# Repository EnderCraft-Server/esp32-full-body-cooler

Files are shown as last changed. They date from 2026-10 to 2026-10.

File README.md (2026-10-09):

# ESP32 全身降温器（背包式水冷） — `esp32-full-body-cooler`

用 ESP32-S3 主控 + 冰袋 + 365 隔膜泵 + 贴身软管循环水，做一件可以背着走的全身降温马甲。

```
冰袋 + 水 -> PET 密封罐 -> 365 泵 -> 8x11 软管（贴身循环）-> 回 PET 罐
                    ^                                  |
                    +---- DS18B20 水温 / 体表温度 ------+
                                  |
            ESP32-S3 -> 继电器 -> 泵间歇启停（慢 PWM）
```

**核心约束**：365 隔膜泵是有刷电机，**不能用 PWM 平滑调速**，只能整段启停。
固件用「回差 + 最短启停时间」做间歇控制 —— 本质是周期以秒/分钟计的慢 PWM。

---

## 仓库结构

```
esp32-full-body-cooler/
├── projects/
│   ├── body-cooler/          ★ 主项目（固件 + 文档 + CAD）
│   │   ├── src/              main / tempsensor / controller / inputs / console
│   │   ├── include/          config.h 是唯一的引脚与参数来源
│   │   ├── docs/             接线、密封、BOM、PCB 简报等 14 篇
│   │   ├── cad/              防折螺旋护套（3D 打印件）+ 生成脚本
│   │   └── wiring.html       交互式接线图（可隐藏单个元件、电流动画）
│   └── hello-s3/             参考工程：芯片自检 + PSRAM 读写测试
├── scripts/                  PlatformIO 工作区工具（见下）
├── skills/esp32-platformio/  可复用的 ESP32 开发 Skill
└── .pio-proxy                本地代理地址（一行），pio.ps1 自动探测启用
```

工作区是**自包含**的：Python venv、PlatformIO core dir、下载缓存、TEMP 全都在文件夹里，
不往用户目录写东西 —— 删掉整个文件夹即彻底卸载。

---

## 快速开始

```powershell
# 编译
.\scripts\pio.ps1 run -d .\projects\body-cooler

# 编译 + 烧录（串口必须显式指定）
.\scripts\pio.ps1 run -d .\projects\body-cooler -t upload --upload-port COM6

# 看串口（pio device monitor 在无 TTY 环境下不可用，用这个）
.venv\Scripts\python.exe .\scripts\serial_term.py --port COM6      # 交互式，能发命令
.venv\Scripts\python.exe .\scripts\serial_capture.py --port COM6 --seconds 10 --reset

# 脚本化发命令并抓回复
.venv\Scripts\python.exe .\scripts\serial_cmd.py --port COM6 --step "scan" --step "status@2"
```

`-d` 必须写在子命令**后面**。

**首次或换机器**：

```powershell
.\scripts\bootstrap.ps1        # 从零重建 venv + PlatformIO（约 700 MB）
```

---

## 硬件要点（踩过坑的，别再踩）

| 事项 | 结论 |
|---|---|
| **继电器触发电平** | 模块是**低电平触发(L)**：IN 短接 GND 吸合 |
| **继电器驱动方式** | 必须**开漏**：吸合推低 0V，释放引脚**高阻**。**绝不能推 3.3V** —— 模块 VCC 是 5V，光耦 LED 阴极接 IN，3.3V 时仍有微弱电流把继电器维持住，表现就是「说 pump=OFF 却一直转」 |
| **泵的电流路径** | `电池+ → 保险丝 → 继电器 COM → NO → 泵+ → 泵− → 电池−`，中间**不能有任何降压板** |
| **续流二极管** | 必须装，1N5822 反向并联在泵两端，阴极朝泵+ |
| **泵保护** | 软管一折就瘪 → 憋压 → 烧泵（已烧 2 台）。三道防线：水流传感器 / `maxrun` 连续运行上限 / **KSD9700 70°C 串在泵电源线上** |
| **贴身软管** | 6×8 硅胶管壁厚只有 1mm，压一下就瘪且撑不开。用 `cad/` 里的**防折螺旋护套**，或嵌进开槽 EVA 垫 |
| **DS18B20 角色映射** | NVS 键名上限 **15 字符**，早期版本用 `role_<16位ROM>`（21 字符）静默写入失败 → 重启后角色丢失 → 安全联锁锁死泵 |

完整踩坑记录见 `projects/body-cooler/docs/BENCH-TEST.md`。

---

## 文档索引

入口：**`projects/body-cooler/README.md`** —— 其中的
**「接线口述（控制端 + 输入端）」**一节是完整的分步接线说明（含逐条接线表，不含电容）。

| 文档 | 内容 |
|---|---|
| `docs/PROJECT-STATUS.md` | 当前状态、已完成 / 待办 |
| `docs/WIRING-CHECKLIST.md` | ★★ **逐触点接线总表：85 根线逐根列，接完打勾，用来事后复原** |
| `docs/BENCH-TEST.md` | ★ 台架测试、事故记录、上电前检查表 |
| `docs/WIRING-GUIDE.md` | 接线总览与电路原理 |
| `docs/GPIO-MAP.md` | GPIO 完整映射（含禁用脚说明） |
| `docs/SEALING-REVIEW.md` | ★ 密封、冷凝、软管被吸瘪的排查 |
| `docs/BOM.md` | 采购清单（具体型号 + 搜索关键词 + 避坑） |
| `docs/PCB-BRIEF.md` | 给硬件工程师的 PCB 设计简报 |
| `docs/diagrams/` | 原理图与示意图（PNG + 生成脚本） |
| `hardware/README.md` | ★ 原理图源文件：嘉立创EDA 导入步骤、网络名一览、元件清单 |
| `cad/README.md` | ★ 3D 打印件：防折螺旋护套 + 转角导弯件 |

---

## 工具链版本

| 组件 | 版本 |
|---|---|
| Python | 3.14.7 |
| PlatformIO Core | 6.2.0 |
| platform | `espressif32@7.1.3` |
| framework | arduino-esp32 2.0.17（ESP-IDF 4.4.7） |
| 编译器 | xtensa-esp32s3 GCC 8.4.0 |
| 烧录器 | esptool 4.11.0 |
| 目标板 | ESP32-S3 **N16R8** — 16 MB QIO flash + 8 MB OPI PSRAM |

---

## 工作区工具（`scripts/`）

| 脚本 | 作用 |
|---|---|
| `pio.ps1` | 唯一的 pio 入口，自动配好所有环境变量与代理 |
| `env.ps1` | 在当前会话 dot-source 出 pio 函数 |
| `bootstrap.ps1` | 从零重建整个环境 |
| `serial_term.py` / `term.ps1` | 交互式串口终端（收 + 发） |
| `serial_capture.py` / `monitor.ps1` | 非交互串口抓取 |
| `serial_cmd.py` | 脚本化发命令并抓回复，支持 `cmd@秒数` |
| `new_project.ps1` | 按模板新建工程 |
| `dsh_sandbox_shim.py` | 修沙箱下 `tempfile.mkdtemp()` 的 PermissionError |

**两个环境适配点，别当成多余代码删掉**：

1. `dsh_sandbox_shim.py` — 沙箱通过父目录的可继承 ACE 授予写权限，
   而 Python 的 `tempfile.mkdtemp()` 会写入显式 DACL 把继承的 ACE 顶掉，
   导致 pip / ensurepip 无法暂存文件。补丁由 `bootstrap.ps1` 装成 venv 的
   `sitecustomize.py`，必须早于 `ensurepip`。
2. `.pio-proxy` — 直连 `dl.registry.platformio.org` 实测 ~17 kB/s，
   走本地代理 ~248 kB/s。`pio.ps1` 探测端口可达后自动启用，不通则回退直连。

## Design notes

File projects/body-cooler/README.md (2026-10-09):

# body-cooler —— ESP32 全身降温器（背包式）

用 ESP32-S3 主控，通过 8x11 软管循环冰水实现全身散热。冰袋方案，不用 TEC。
**365 隔膜泵是有刷电机，只能整段启停，不能 PWM 平滑调速** —— 固件用
「回差 + 最短启停时间」做间歇控制，本质是**周期以秒/分钟计的慢 PWM**。

```
冰袋 + 500ml 水 -> PET 密封罐 -> 365 泵 -> 8x11 软管（贴身循环）-> 回 PET 罐
                        ^                                    |
                        └──── DS18B20 测水温 / 体表温度 ──────┘
                                        |
                                  ESP32 -> 继电器 -> 泵间歇启停
```

---

## 目录结构

```
body-cooler/
  platformio.ini            PlatformIO 配置（ESP32-S3-N16R8）
  include/
    config.h                引脚分配、默认参数、编译开关
    tempsensor.h            DS18B20 多探头异步采集 + 角色映射
    controller.h            水泵控温状态机
    inputs.h                v2 输入层（电池/水流/液位/急停/漏水）
    console.h               串口命令行
  src/
    main.cpp                主循环、状态灯、蜂鸣器、备用继电器
    tempsensor.cpp
    controller.cpp
    inputs.cpp
    console.cpp
  docs/
    WIRING-GUIDE.md         ★ 接线总览与电路原理（配三张原理图）
    ORDER-REVIEW.md         京东订单核对（哪些买错、还要补什么）
    GPIO-MAP.md             ★ GPIO 完整映射表（v1/v2/禁用脚/接线图）
    UPGRADE-PLAN.md         ★ 分阶段升级方案（P0~P4）
    BOM.md                  ★ 采购清单（具体型号 + 搜索关键词 + 避坑）
    WIRING-REVIEW.md        接线与电源审查（必读，有 6 处必须改）
    SEALING-REVIEW.md       ★ 密封、冷凝、软管被吸瘪的排查
    BRINGUP.md              桌面测试 7 步流程（必读，别跳步）
    PCB-BRIEF.md            ★ PCB 设计规格书（交给硬件工程师画板用）
    WIRING-CHECKLIST.md     ★★ 逐触点接线总表（85 根线，接完打勾，事后复原用）
    BENCH-TEST.md           ★★ 台架测试 + 事故记录 + 上电前 10 条检查
    PROJECT-STATUS.md       当前状态：已完成 / 卡脖子的 / 下一步
  docs/diagrams/            原理图与示意图（PNG + 生成脚本 fig*.py）
    fig1_power_pump.png     图1 电源分配与水泵主回路
    fig2_esp32_wiring.png   图2 ESP32-S3 全部引脚接线
    fig3_water_loop.png     图3 水路走向与保温结构
    fig4_build_methods.png  图4 搭建方式对比
    fig5_system_schematic.png 图5 整机系统原理图
    fig6_terminal_wiring.png 图6 端子排接线图
    fig7_wearable.png       图7 贴身段固定方案
  hardware/                 ★ 原理图源文件（嘉立创EDA 可导入，详见 hardware/README.md）
    body-cooler-kicad.zip   ★ 导入用这个（.sch + .lib + 缓存库，已打包）
    body-cooler.sch         KiCad 旧版 EESchema v4 原理图
    body-cooler.lib         自定义符号库（15 个符号）
    make_schematic.py       生成器 + 自检（悬空端点/T接点/交叉）
    render_schematic.py     不依赖 EDA 软件的 PNG 预览
  cad/                      3D 打印件：防折螺旋护套 + 转角导弯件（详见 cad/README.md）
    make_sleeve.py          参数化生成 STL（纯 Python，无第三方依赖）
    sleeve_*.stl            四种规格：缝宽 2.0 / 1.5 / 1.0 mm
    render_preview.py       Blender headless 渲染 + 网格检查
  wiring.html               ★★ 交互式接线指南（双击用浏览器打开）
```

> **搭建方式已定为「接线端子方案」**（不用面包板、不用画板）。
> 67 根线的逐条接线表在 `wiring.html` —— 每行标明「从元件上的哪个丝印 → 到元件上的哪个丝印」，
> 可以边接边打勾，进度自动记住。

---

## 快速开始

```powershell
# 都在工作区根目录 D:\dsh_Workspaces\ESP32 下执行

# 编译
.\scripts\pio.ps1 run -d .\projects\body-cooler

# 编译 + 烧录（串口必须显式指定：UART 口是 CH343 -> COM5，原生 USB 口 -> COM6）
.\scripts\pio.ps1 run -d .\projects\body-cooler -t upload --upload-port COM6

# 看串口（不要用 pio device monitor，在无 TTY 的环境里会报错）
.\.venv\Scripts\python.exe .\scripts\serial_term.py   --port COM6              # 交互式
.\.venv\Scripts\python.exe .\scripts\serial_capture.py --port COM6 --seconds 10 --reset
.\.venv\Scripts\python.exe .\scripts\serial_cmd.py   --port COM6 --step "scan" --step "status@2"
```

串口 115200，输入 `help` 看命令表，输入 `status` 看状态。

---

## 引脚分配

当前板级 `BOARD_REV = 2`，是 rev1 的**纯超集** —— 没有移动任何已有引脚。

| 功能 | GPIO | 备注 |
|---|---|---|
| DS18B20 单总线（5 探头并联） | 4 | 4.7k 上拉到 **3V3** |
| 继电器 1 → 水泵 | 5 | 主输出 |
| 继电器 2 / 3 / 4 / 5 → 备用 | 6 / 7 / 15 / 16 | `aux 1` ~ `aux 4` |
| 有源蜂鸣器（可选） | 17 | |
| 漏水检测（可选） | 18 | `ENABLE_LEAK_SENSOR` |
| 电池电压 (ADC1_CH0) | 1 | 分压 100k / 18k |
| I2C SDA / SCL | 8 / 9 | OLED / INA219 |
| 水流传感器 | 10 | 信号需 10k+15k 分压 |
| 液位开关 | 11 | 内部上拉 |
| 急停按钮（常闭） | 21 | 内部上拉 |
| 按键 A / B | 38 / 39 | |
| 板载状态灯 | 48 | DevKitC-1 v1.0 是 WS2812 |

**禁用的引脚**：0 / 3 / 45 / 46（strapping）、19 / 20（原生 USB）、26 ~ 32（flash）、
33 ~ 37（OPI PSRAM）、43 / 44（UART0）。

> 25 个可用引脚里 rev2 用了 18 个，还剩 7 个空闲。
> **完整的引脚表、接线图、ADC 注意事项见 `docs/GPIO-MAP.md`。**
>
> 所有 v2 新增输入默认**关闭**（`ENABLE_xxx = 0`）—— 没接线时引脚悬空会误报。
> 接好一根、验证过读数，再把对应开关改成 1。

---

## 接线口述（控制端 + 输入端）

> 本节**不含任何电容**（陶瓷、电解一律不要）。省掉它们的后果写在最后 5.5 小节。

### 5.1 先记三条铁律

**① 共地。** ESP32 的 GND、继电器模块的 GND、降压板的 GND、电池负极，必须是同一个节点。
这是最容易漏的一根线 —— 漏了以后 GPIO 推什么电平对继电器模块都没有意义。
症状就是「说 pump=ON 却不吸合、说 pump=OFF 反而一直转」。
实测手法：万用表通断档量 `ESP32 的 GND 脚` 和 `继电器模块的 GND`，必须 0Ω。

**② 泵的电流路径上只能有保险丝和继电器触点。**

```
电池+ → 5A 保险丝 → 继电器 COM → NO → 泵+ → 泵− → 电池−
```

中间**不能有降压板**，也不能让泵的电流流经信号地。这是上次烧泵烧板的直接原因。
另外泵是有刷电机 = 大电感，**续流二极管必须装**：1N5822 反向并联在泵两端，
**阴极（有环那一端）朝泵+**。不装的话，触点断开的瞬间会有几百伏反峰，几个月的功夫触点就烧出麻点。

**③ 继电器是低电平触发**，而且要用**开漏驱动**。

```
吸合：GPIO5 推低  →  IN = 0V
释放：GPIO5 变高阻 →  IN 由 10k 上拉到模块的 5V
```

**绝对不要在释放时推 3.3V。** 模块 VCC 是 5V，光耦 LED 的阴极接在 IN 上，
IN 停在 3.3V 时 LED 上还有 5 − 3.3 − 1.2 ≈ 0.5V 的压差，微弱电流足以把继电器维持住 ——
表现就是「固件说 pump=OFF，泵却一直转」。固件已经默认开漏（`relay od`），
配上一只 `IN ──[10k]── 模块 VCC(5V)` 就彻底干净。

---

### 5.2 控制端（ESP32 往外发指令）

控制端一共就 **7 根信号线**，全部是单向输出：

| 信号 | ESP32 引脚 | 去向 | 固件命令 |
|---|---|---|---|
| 水泵继电器 | **GPIO5** | 继电器 1 `IN` | 自动 / `pump on` / `pump off` |
| 备用继电器 1 | GPIO6 | 继电器 2 `IN` | `aux 1 on\|off` |
| 备用继电器 2 | GPIO7 | 继电器 3 `IN` | `aux 2 on\|off` |
| 备用继电器 3 | GPIO15 | 继电器 4 `IN` | `aux 3 on\|off` |
| 备用继电器 4 | GPIO16 | 继电器 5 `IN` | `aux 4 on\|off` |
| 有源蜂鸣器（可选） | GPIO17 | 蜂鸣器 `+` | 报警时自动响 |
| 板载 WS2812 状态灯 | GPIO48 | 不用接线 | 板载 |

**每个继电器模块要接 3 根线**，5 个模块 = 15 根：

```
ESP32 J1 GPIOx ───────────────► 模块 IN
5V_A 轨        ───────────────► 模块 VCC     ← 必须 5V，不是 3V3
GND 轨         ───────────────► 模块 GND
```

**每个模块的 IN 再各加一只 10k 上拉到模块自己的 VCC(5V)** —— 一共 5 只 10k：

```
模块 IN ──[10k]── 模块 VCC
```

> 为什么必须加：ESP32 复位期间 GPIO 是高阻，IN 会悬空。悬空本身对低电平触发模块
> 等于「没电流」，是安全的；但水泵电刷的干扰能把它带偏。有了这只上拉，
> 悬空状态被明确拉到 5V，彻底截止。

#### 逐条接线表（控制端）

| # | 从（元件丝印） | 到（元件丝印） | 备注 |
|---|---|---|---|
| 1 | ESP32 `GPIO5` | 继电器 1 `IN` | 水泵主输出 |
| 2 | ESP32 `5V` | 继电器 1 `VCC` | 见下方 5V 说明 |
| 3 | ESP32 `GND` | 继电器 1 `GND` | |
| 4 | 继电器 1 `IN` | 10k 一端 | |
| 5 | 10k 另一端 | 继电器 1 `VCC` | |
| 6 ~ 10 | 同上 5 根 | 继电器 2 | `IN` 换 **GPIO6** |
| 11 ~ 15 | 同上 5 根 | 继电器 3 | `IN` 换 **GPIO7** |
| 16 ~ 20 | 同上 5 根 | 继电器 4 | `IN` 换 **GPIO15** |
| 21 ~ 25 | 同上 5 根 | 继电器 5 | `IN` 换 **GPIO16** |
| 26 | ESP32 `GPIO17` | 蜂鸣器 `+` | 可选 |
| 27 | ESP32 `GND` | 蜂鸣器 `−` | 可选 |

> **5V 从哪来**：ESP32 和 5 个继电器模块都用 `5V_A`，来自 12V→5V 降压板。
> 更稳的做法是**两条独立 5V 轨**：`5V_A` 只给继电器线圈，`5V_B` 只给 ESP32，
> 各自的 GND 再单点汇到一起 —— 这样继电器吸合的压降不会把 MCU 打复位。
> **泵绝不从降压板取电。**

---

### 5.3 输入端

输入端分三类：单总线、模拟量、开关量。

#### （1）DS18B20 单总线 —— GPIO4

```
3V3 ──[4.7k]──┬──────────────────────────── GPIO4
              │
            ┌─┴─┬─────┬─────┬─────┐
          [探头1][探头2][探头3][探头4][探头5]      5 个全部并联
            └─┬─┴─────┴─────┴─────┘
              │
             GND
```

每个探头三根线：`VDD → 3V3`、`GND → GND`、`DQ → GPIO4`。
**4.7k 上拉只加一只**，接在总线靠 ESP32 的那一端，而且**上拉到 3V3，不是 5V**。

> 挂上去以后用串口 `scan` 看有几个探头，再用 `map skin_chest 0` 之类把 ROM 绑到角色上
> （`map` 会自动写进 NVS，掉电不丢）。
> 目前手上只有 **3 个防水探头，缺 2 个**，总线上现在只扫到 1 个。

#### （2）电池电压 —— GPIO1（可选，`ENABLE_BATT_SENSE` 默认 0）

```
BAT+ ──[R1 100k]──┬── GPIO1 (ADC1_CH0)
                  │
                [R2 18k]
                  │
                 GND
```

分压比 = (100 + 18) / 18 = **6.556**，12.6V → 1.92V，9.0V → 1.37V。
**必须用 ADC1（GPIO1~10）** —— ESP32-S3 的 ADC2（GPIO11~20）在 WiFi 开启时不可用。

#### （3）水流传感器 —— GPIO10（可选，默认关闭，但★强烈建议装）

```
5V_A ──[2.2k]──┬── 传感器 OUT
               │
             [10k] R1
               │
               ├──────── GPIO10
               │
             [20k] R2
               │
              GND
```

高电平 = 5 × 20 / (2.2 + 10 + 20) = **3.11V**，ESP32-S3 的输入门限是 2.475V，留了余量。
传感器是开集输出，**那只 2.2k 不能省**（只靠传感器内部上拉只有 2.50V，贴着门限）。
接好用万用表量 GPIO10 对 GND 的高电平，**要在 2.8V 以上**。

> **这是防烧泵最有效的一道防线**：泵在转、但 15 秒内读不到水流 → 立刻停泵 + 强制休息。
> 已经烧掉 2 台泵了，有条件优先装这个。

#### （4）开关量 —— 全部是「引脚 — 开关 — GND」，用 MCU 内部上拉

| 信号 | GPIO | 接法 | 有效状态 |
|---|---|---|---|
| 液位开关（浮子簧片） | **GPIO11** | 引脚 — 开关 — GND | 低 = 有水 |
| 漏水检测 | **GPIO18** | 引脚 — 裸铜线A — 2mm间隙 — 裸铜线B — GND | 低 = 遇水 |
| 急停 / 总电源开关 | **GPIO21** | 引脚 — **常闭 NC** 开关 — GND | **高 = 按下或线断** |
| 按键 A / B | 38 / 39 | 引脚 — 轻触开关 — GND | 低 = 按下（固件暂未使用） |

**急停为什么用常闭**：不按时触点闭合到 GND，引脚读低；按下时断开、被上拉拉高。
这样「按下」和「线断了」是同一种结果 —— 失效安全。用常开的话线断了没人知道，急停形同虚设。

> 软件急停依赖单片机活着。**强烈建议把开关的另一组触点串在泵的 12V 硬回路里**，
> 这样即使 MCU 死机，按下去也能物理切断。

#### 逐条接线表（输入端）

| # | 从（元件丝印） | 到（元件丝印） | 备注 |
|---|---|---|---|
| 1 | ESP32 `3V3` | 4.7k 一端 | DS18B20 总线唯一的上拉 |
| 2 | 4.7k 另一端 | ESP32 `GPIO4` | |
| 3 | ESP32 `GPIO4` | 探头 `DQ`（黄） | |
| 4 | ESP32 `3V3` | 探头 `VDD`（红） | |
| 5 | ESP32 `GND` | 探头 `GND`（黑） | |
| 6 ~ 8 | 同 3 ~ 5 | 探头 2 / 3 并联 | 项目还缺 2 个探头 |
| 9 | 电池 `BAT+` | 100k 一端 | 可选 |
| 10 | 100k 另一端 | ESP32 `GPIO1` | |
| 11 | ESP32 `GPIO1` | 18k 一端 | |
| 12 | 18k 另一端 | ESP32 `GND` | |
| 13 | 5V_A 轨 | 2.2k 一端 | 水流，可选 |
| 14 | 2.2k 另一端 | 传感器 `OUT` | |
| 15 | 传感器 `OUT` | 10k 一端 | |
| 16 | 10k 另一端 | ESP32 `GPIO10` | |
| 17 | ESP32 `GPIO10` | 20k 一端 | |
| 18 | 20k 另一端 | ESP32 `GND` | |
| 19 | 传感器 `VCC`（红） | 5V_A 轨 | |
| 20 | 传感器 `GND`（黑） | ESP32 `GND` | |
| 21 | ESP32 `GPIO11` | 浮子开关一端 | 可选 |
| 22 | 浮子开关另一端 | ESP32 `GND` | |
| 23 | ESP32 `GPIO18` | 裸铜线 A | 可选，漏水 |
| 24 | 裸铜线 B | ESP32 `GND` | A / B 间隔 2~3mm |
| 25 | ESP32 `GPIO21` | 常闭开关一端 | 可选 |
| 26 | 常闭开关另一端 | ESP32 `GND` | |

---

### 5.3.1 原理图源文件

上面这些连接全部已经画成可导入的原理图：`hardware/body-cooler-kicad.zip`。

嘉立创EDA：**文件 → 导入 → KiCAD**，选这个 zip（不能直接选 `.sch`，官方要求必须打成 zip 且带库文件）。
也可以用 KiCad 直接开 `hardware/body-cooler.sch`。

画法上遵守的规则：**每一处点对点连接都有网络标签**、**不含任何陶瓷/电解电容**、
继电器按低电平触发 + 开漏驱动画、泵的电流路径上只有保险丝和触点。详见 `hardware/README.md`。

---

### 5.4 接到电脑调试

| 项目 | 说明 |
|---|---|
| **UART 口**（丝印 `UART`） | 板载 CH343 → `USB-Enhanced-SERIAL CH343 (COM5)` |
| **原生 USB 口**（丝印 `USB`） | `USB 串行设备 (COM6)`；固件开了 `ARDUINO_USB_CDC_ON_BOOT=1`，**控制台走这里** |
| 波特率 | 115200 |
| 烧录 | `--upload-port COM6`。串口号会变，接之前先 `Get-CimInstance Win32_PnPEntity` 查一下 |

---

### 5.5 省掉电容的代价（知道就行，不拦你）

| 位置 | 原本要加 | 不加会怎样 |
|---|---|---|
| 电池分压 R2 上 | 100nF 陶瓷 | 100k / 18k 的并联阻抗约 15k，对 ESP32 的 ADC 偏高，采样电容充电不足会**读数偏低**。固件已经做 8 次平均 + 用 `analogReadMilliVolts()` 读出厂校准值，够用 |
| 泵接线端子 | 100nF 陶瓷 | 电刷高频噪声没有就近旁路，靠续流二极管 + 两条独立 5V 轨硬扛 |
| 5V 轨 | 电解电容 | 继电器吸合的瞬时压降没有本地储能，母线塌陷更容易把 ESP32 打复位。**如果实测出现复位，第一个补这个** |

---

## 控制逻辑

### 三层保护（优先级从高到低）

1. **安全联锁** —— 可打断最短运行时间，立即停泵：
   体表低于 `skinLow`、水温低于 `waterMin`、读数全部失效、漏水。
   带 1 度回差自动恢复（漏水除外，必须 `clear`）。
2. **最短运行 / 最短停机** —— 保护继电器触点和泵的阀片。
   默认 20 秒 / 30 秒，即每小时最多约 72 次启停。
3. **需求控制** —— 回差启停（默认）或时间比例。

### 为什么不能用 PWM

有刷电机的换向器和电刷在低频 PWM 下会剧烈打火、发热、噪音大，
而且隔膜泵在低速下流量急剧下降、阀片拍打异常。所以只能用整段启停，
靠**时间比例**模拟调速 —— 一个周期几分钟，远大于电机的热时间常数，
电机每次都按额定转速工作，没有任何副作用。

### 状态机

```
STANDBY   待机（总开关关 / 手动强制关）
MONITOR   体表未到开泵阈值，泵停
REST      泵停，但在等最短停机时间结束
PUMPING   泵运行中
FAULT     安全停机（过冷 / 无水 / 传感器失效 / 漏水）
```

### 默认参数

| 参数 | 默认 | 说明 |
|---|---|---|
| `target` | 33.0 度 | 体表目标温度 |
| `band` | 1.0 度 | 回差：33.5 开泵 / 32.5 停泵 |
| `slow` | 30.0 度 | 体表下限，低于则强制停泵 |
| `shigh` | 38.0 度 | 体表上限，高于则报警 |
| `wmin` | 8.0 度 | 水温下限（**建议实测后调到 10 ~ 12**） |
| `wmax` | 32.0 度 | 水温上限，高于则报警（冰袋化了） |
| `mon` / `moff` | 20s / 30s | 最短运行 / 最短停机 |
| `ice` | 8 min | 冰袋有效性评估窗口 |
| `mode` | 0 | 0 = 回差启停，1 = 时间比例 |

设好之后 `savecfg` 保存到 NVS，掉电不丢。

### 自检与报警

| 报警 | 触发条件 |
|---|---|
| `SKIN_HIGH` | 体表 >= 38 度：冷却失效，注意中暑 |
| `SKIN_LOW` | 体表 <= 30 度：**立即停泵** |
| `WATER_LOW` | 出水温 <= 8 度：**立即停泵**，防冷损伤 |
| `WATER_HIGH` | 出水温 >= 32 度：冰袋化了 / 没水 |
| `DRY_RUN` | 泵转了 60 秒以上，最冷点还是不冷：干转 / 气堵 |
| `ICE_MELT` | 连续运行 8 分钟，回水出水温差 < 0.5 度且体表仍热 |
| `NO_SENSOR` / `SENSOR_FAULT` | 探头缺失或读数全废 -> 拒绝自动控温 |
| `LEAK` | 漏水（可选功能） |

### 状态灯（板载 WS2812）

| 颜色 | 含义 |
|---|---|
| 蓝，3 秒一闪 | 待机 |
| 绿，1 秒一闪 | 监控中，泵停 |
| 黄，双闪 | 泵停，在等最短停机 |
| 青，快闪（2Hz） | **泵运行中** |
| 橙，双闪 | 有报警 |
| 红，三连闪 | 故障，泵已强制停 |

---

## 串口命令

| 命令 | 作用 |
|---|---|
| `help` | 完整命令表 |
| `status` / `s` | 打印一次完整状态 |
| `scan` | 扫描总线，列出 ROM / 角色 / 温度 |
| `map <role> <idx\|ROM>` | 绑定探头角色（water_out / water_ret / skin_chest / skin_back / ambient） |
| `automap` / `clearroles` / `roles` | 批量映射 / 清空 / 查看 |
| `save` | 角色映射写入 NVS |
| `enable on\|off` | 控温总开关 |
| `pump on\|off\|auto` | 手动强制水泵（台架排空气用） |
| `clear` | 清除安全联锁 / 漏水 / 急停 |
| `aux <1-4> on\|off` | 备用继电器手动开关 |
| `target` / `band` / `slow` / `shigh` / `wmin` / `wmax` | 各项阈值 |
| `mon` / `moff` / `ice` / `flow` / `mode` | 时间参数与模式 |
| `showcfg` / `savecfg` / `defaults` | 查看 / 保存 / 恢复设定 |
| `log on\|off` / `rate <ms>` | 周期性状态输出 |
| `stats` | 累计运行时长与启动次数 |
| `inputs` | 查看所有可选输入的引脚状态 |
| `batt` | 电池电压（需 `ENABLE_BATT_SENSE`） |
| `flow` | 实测流量 / 累计水量（需 `ENABLE_FLOW_SENSOR`） |
| `flowcal <脉冲/升>` | 水流传感器标定（YF-S401=5880，YF-S201=450） |

---

## 审查结论：动手前必须先解决的 5 件事

详细内容见 `docs/WIRING-REVIEW.md` 和 `docs/SEALING-REVIEW.md`。

1. **泵两端加续流二极管**（1N5408，阴极接 +12V）。
   不加的话，触点拉弧会缩短继电器寿命，反峰还会让 ESP32 随机复位。
2. **继电器 IN 加 10k 上拉 / 下拉**，保证上电瞬间泵绝对不转。
3. **暴露段软管套保温棉，罐子套保温套**。
   不保温时暴露段会白白漏掉约 44W 冷量，和体表实际能带走的热量同一量级 —— **续航直接砍半**。
4. **10 米软管裁到 4 ~ 5 米**。8mm 内径 10 米管的内容积约 0.50 升，和水箱一样大。
5. **锂电池加 5A 保险丝 + 3S BMS**，电池和水箱物理隔开，充电时远离水路。

### 关于效果的预期

按 500g 有效冰量估算，系统有效冷量约 214 kJ：

| 状态 | 续航 |
|---|---|
| 静息（带走约 40W） | 约 89 分钟 |
| 活动（带走约 60W，冰消耗更快） | 约 30 ~ 45 分钟 |

**这是「延缓升温 / 局部降温」装备，不是「全身空调」。**
想延长续航，按性价比排序：加保温 > 加大水量 > 加冰量 > 缩短软管。

---

## 还没有做的部分（下一步可以考虑）

* 蓝牙 / WiFi 手机端看温度和曲线（3 块 S3 里可以拿一块做无线监视端）
* 液位开关 / 水流开关，从根本上杜绝干转
* TEC1-12712 那 5 片先留着 —— 继电器 2 ~ 5 和固件的 `aux` 命令已经给它们留好位置了
* 把 3 个 PET 盒串联成 1.5L 大水箱，延长续航

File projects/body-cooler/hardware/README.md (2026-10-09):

# 原理图源文件（嘉立创EDA 可直接导入）

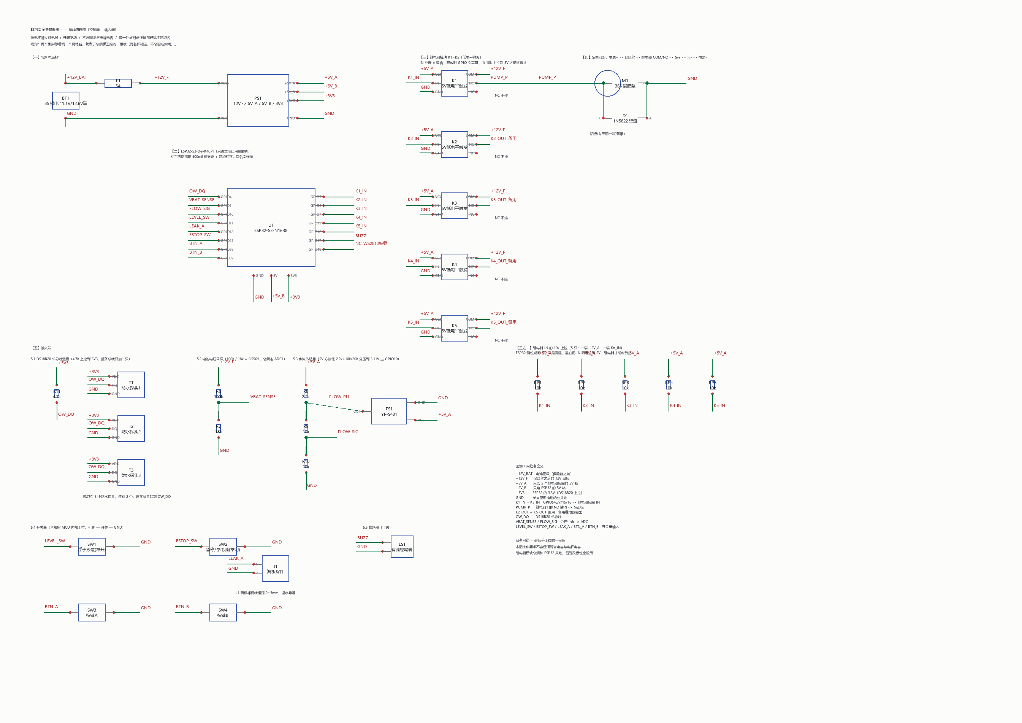
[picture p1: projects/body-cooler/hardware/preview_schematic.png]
原理图预览


## 为什么是 KiCad 旧版格式

你要的 `.schematic`，实际对应的是 **KiCad / EESchema 原理图**。查过嘉立创EDA的导入文档：

> 「嘉立创EDA支持KiCAD文件导入，但是**仅支持 KiCAD v4.06 及以上版本**的文件。」
> 「**KiCAD v5.1.3 后的版本文件格式有更新，可能会导入失败**，建议先用低版本保存再导入试试。」
> 「导入的KiCAD文件需要先**压缩为zip格式**，然后再导入。」
> 「如果要导入原理图，则压缩包内**需要包含库文件或库文件夹**。」

所以这里生成的是 **v4 的 `.sch` + `.lib`**，并已经打好 zip。不用 `.kicad_sch`（那是 v6+ 的新格式，可能导入失败）。

## 文件

| 文件 | 说明 |
|---|---|
| `body-cooler.sch` | 原理图主体，EESchema v4 文本格式 |
| `body-cooler.lib` | 自定义符号库（15 个符号全在里面） |
| `body-cooler-cache.lib` | 工程缓存库，内容和上面一样 —— 导入时靠它认符号 |
| **`body-cooler-kicad.zip`** | ★ **导入用这个**（`body-cooler/` 目录 + 三个文件） |
| `make_schematic.py` | 生成器，改参数重跑即可 |
| `render_schematic.py` | 用自己的数据画 PNG 预览（不依赖 EDA 软件） |

## 导入步骤

### 嘉立创EDA 标准版
1. 顶部菜单 **文件 → 导入 → KiCAD**
2. 选 `body-cooler-kicad.zip`（**必须是 zip，不能直接选 .sch**）
3. 导入后会把 PWR_FLAG 之类转成元件，要删就删

### 嘉立创EDA 专业版
1. **文件 → 导入 → KiCad**，同样选 zip

### 或者用 KiCad 自己打开
直接开 `body-cooler.sch` 即可（KiCad 5/6/7/8 都能读 legacy 格式并自动迁移）。

## 这张图遵守的规则

1. **每一处点对点连接都有网络标签** —— 两个引脚标着同一个名字，就表示必须手工接的一根线。
2. **不含任何陶瓷电容与电解电容**（按你的要求去掉了分压旁路电容、泵端子高频电容、5V 轨储能电容）。
3. 继电器按**低电平触发 + 开漏驱动**画：吸合推低 0V，释放引脚高阻、由 10k 上拉到 5V。
4. 泵的电流路径上**只有保险丝和继电器触点**，中间没有任何降压板。

## 网络名一览

| 网络 | 含义 | 连接的两端 |
|---|---|---|
| `+12V_BAT` | 电池正极（保险丝之前） | BT1.+ ↔ F1.1 |
| `+12V_F` | 保险丝之后的 12V 母线 | F1.2 ↔ PS1.VIN+ / K1~K5.COM / R6.1 |
| `+5V_A` | 只给继电器线圈的 5V 轨 | PS1.3 ↔ K1~K5.VCC / RP1~RP5.1 / R8.1 / FS1.VCC |
| `+5V_B` | 只给 ESP32 的 5V 轨 | PS1.4 ↔ U1.5V |
| `+3V3` | 3.3V | PS1.5 ↔ U1.3V3 / R11.1 / T1~T3.VDD |
| `GND` | 单点星形接地的公共地 | 多处 |
| `K1_IN`~`K5_IN` | GPIO5/6/7/15/16 → 继电器线圈 IN | U1 ↔ K1~K5.IN，并经 RP1~RP5 上拉到 +5V_A |
| `PUMP_P` | 继电器1 的 NO 触点 → 泵正极 | K1.NO ↔ M1.+ |
| `K2_OUT`~`K5_OUT_备用` | 备用继电器输出 | K2~K5.NO |
| `OW_DQ` | DS18B20 单总线 | U1.GPIO4 ↔ R11.2 ↔ T1~T3.DQ |
| `VBAT_SENSE` | 电池分压中点 → ADC | R6.2 ↔ R7.1 ↔ U1.GPIO1 |
| `FLOW_PU` | 水流分压上节点 | R8.2 ↔ R9.1 ↔ FS1.OUT |
| `FLOW_SIG` | 水流分压中点 → ADC | R9.2 ↔ R10.1 ↔ U1.GPIO10 |
| `LEVEL_SW` | 浮子液位开关 | SW1.1 ↔ U1.GPIO11 |
| `ESTOP_SW` | 急停/总电源开关（常闭） | SW2.1 ↔ U1.GPIO21 |
| `LEAK_A` | 漏水探针 | J1.1 ↔ U1.GPIO18 |
| `BTN_A` / `BTN_B` | 按键 A / B | SW3.1 / SW4.1 ↔ U1.GPIO38 / GPIO39 |
| `BUZZ` | 有源蜂鸣器 | LS1.+ ↔ U1.GPIO17 |

## 元件清单

| 位号 | 型号 / 值 | 说明 |
|---|---|---|
| U1 | ESP32-S3-DevKitC-1 (N16R8) | 主控（图上只画了本项目用到的 18 个脚） |
| BT1 | 3S 锂电 11.1V / 12.6V 满 | |
| F1 | 5A 保险丝 | 泵主回路 |
| PS1 | 12V → 5V_A / 5V_B / 3V3 降压模块 | |
| K1~K5 | 5V 光耦继电器模块，低电平触发 | K1 驱动水泵，K2~K5 备用 |
| RP1~RP5 | 10k | 继电器 IN 上拉到 +5V_A |
| M1 | 365 隔膜泵 | |
| D1 | 1N5822 肖特基 | 续流，阴极朝泵正极 |
| R11 | 4.7k | DS18B20 总线上拉（只加一只，拉到 3V3） |
| T1~T3 | DS18B20 防水探头 | 项目共需 5 个，现只有 3 个 |
| R6 / R7 | 100k / 18k | 电池分压，比 6.556:1 |
| R8 / R9 / R10 | 2.2k / 10k / 20k | 水流传感器分压 |
| FS1 | YF-S401 水流传感器 | |
| SW1 | 浮子液位开关（常开） | |
| SW2 | 急停 / 总电源开关（常闭） | 失效安全：按下和线断是同一种结果 |
| SW3 / SW4 | 轻触按键 | 固件暂未使用 |
| J1 | 漏水探针（两根裸铜线，间隔 2~3mm） | |
| LS1 | 有源蜂鸣器 | 可选 |

## 生成器自检

`make_schematic.py` 跑完会自动校验，当前结果：

```
符号 15  元件 32  导线 101  标签 94  引脚 108
悬空导线端点 0
未标注的 T 形接点 0
未接线引脚 5   [K1.NC K2.NC K3.NC K4.NC K5.NC]   <- 继电器常闭触点，故意不接
交叉(不相连) 0
```

校验内容：

* **悬空导线端点** —— 有没有画了线但两头都没接到东西（会变成飞来线）
* **未标注的 T 形接点** —— 端点落在别的线上却没标签，容易看漏
* **未接线引脚** —— 除故意留空的 NC 外都应为 0
* **交叉** —— 两条正交线段内部交叉（不算连接，但太多说明版面乱）

## 重新生成

```powershell
.venv\Scripts\python.exe .\projects\body-cooler\hardware\make_schematic.py
.venv\Scripts\python.exe .\projects\body-cooler\hardware\render_schematic.py
```

几何全在 `make_schematic.py` 里：

| 位置 | 内容 |
|---|---|
| `SYMS` 定义段 | 15 个符号的图形与引脚（引脚表同时用于连线和自检） |
| 版面段 | 每个元件的坐标、导线、网络标签、注释 |

想改引脚、加符号、挪位置，改完重跑；自检会告诉你有没有画错。

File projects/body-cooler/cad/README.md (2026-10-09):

# 防折螺旋护套（3D 打印件）

## 它解决什么问题

6×8 硅胶管**一折就瘪，瘪了以后即使泵有压力也撑不开**，结果是泵憋压 → 电机过热 → 烧泵。

这个护套套在硅胶管外面，一次解决两件事：

1. **径向撑住** —— 1.7mm 的硬壳把管壁撑住，背包压、手捏、绑带勒都不会瘪；
2. **限制弯曲半径** —— 弯曲时螺旋缝在**内侧闭合并顶死**，管子再也弯不到会打死折的角度。

```
        直的                      弯的
   ┌───────────┐            ╭───────────╮
   │ ~~~~~~~~~ │           ╱ ~~~~~~~~~ ╲
   │  硅胶管    │          │  硅胶管     │
   │ ~~~~~~~~~ │           ╲ ~~~~~~~~~ ╱
   └───────────┘            ╰───────────╯
     螺旋缝          外侧：缝张开     内侧：缝闭合 -> 顶死，不能继续弯
```

## 文件

| 文件 | 缝宽 | 长度 | 最小弯曲半径 Rmin | 缝处材料应变 | 说明 |
|---|---|---|---|---|---|
| `sleeve_A_flex.stl`  | 2.0 mm | 150 mm | **24 mm** | 4.7% | 最软最好盘，但缝处应变偏大 |
| `sleeve_B_mid.stl` | 1.5 mm | 150 mm | **32 mm** | 3.3% | ★ **推荐**，两端都合适 |
| `sleeve_C_rigid.stl` | 1.0 mm | 150 mm | **48 mm** | 2.0% | 最硬最抗瘪，但只能缓弯 |
| `sleeve_A_short.stl` | 2.0 mm | 60 mm  | 24 mm | 4.7% | 先打这个试手感 |

**Rmin 和材料应变是互斥的**：缝越宽，能弯得越急，但缝两侧的材料被拉伸得越厉害、越容易疲劳。
`Rmin × 应变 ≈ 0.85 mm` 是这套几何的硬约束，改不了。

* 想更耐弯 → 选 A（缝 2.0），代价是缝处应变 4.7%，PETG 长期反复弯可能疲劳开裂；
* 想更耐久 → 选 C（缝 1.0），代价是最小弯曲半径 48mm，盘不紧。

**推荐从 `sleeve_B_mid` 开始**，或者先打一段 `sleeve_A_short`（60mm）试手感。

## 关键尺寸

| 项目 | 值 | 说明 |
|---|---|---|
| 内径 | 8.6 mm | 8mm 硅胶管 + 0.6mm 装配间隙 |
| 外径 | 12.0 mm | |
| 壁厚 | 1.70 mm | |
| 螺距 | 8.0 mm | |
| 缝宽 | 2.0 / 1.5 / 1.0 mm | 见上表 |

## 打印参数

| 项 | 建议 |
|---|---|
| 材料 | **PETG**（必须）。PLA 太脆，反复弯会裂；TPU 太软撑不住 |
| 摆放 | **竖着立起来打**（螺旋轴沿 Z），不需要任何支撑 |
| 层高 | 0.2 mm |
| 壁厚 | 2 圈（0.8mm）就够，别开填充 |
| 底边 | **加 brim**。150mm 高、12mm 粗的细高件接触面很小，容易倒 |
| 速度 | 降到 60%，细高件高速打会晃 |
| 后处理 | 打完用手弯一弯，把螺旋缝里可能粘连的地方掰开 |

## 怎么用

1. **先把护套套到硅胶管上，再去接两端的宝塔头** —— 螺旋缝是连续的一条，管子没法从侧面塞进去。
   如果管子已经接好了：用斜口钳沿螺旋缝剪开一段，掰开套上去，再用扎带箍一下。
2. 1 米管子约需要 `1000 / 150 ≈ 7` 段。
3. 分段之间**对接**即可，接口缠一圈电工胶带或套一小段热缩管。
4. 套好以后管子可以盘成 R ≥ 对应 Rmin 的蛇形。**弯到顶死时会明显感觉“到头了”** —— 那就是限位在起作用，别硬掰。
5. 固定到身上：护套外径 12mm，用尼龙扎带或松紧带环固定 —— **环要比管子松 1~2mm，别勒死**。

## 重新生成 / 改参数

```
# 改 make_sleeve.py 里 VARIANTS 表的参数后：
.venv\Scripts\python.exe .\projects\body-cooler\cad\make_sleeve.py

# 渲染预览（Blender headless）
& 'E:\Blender\blender.exe' -b --factory-startup -P .\projects\body-cooler\cad\render_preview.py -- `
    .\projects\body-cooler\cad\sleeve_B_mid.stl .\projects\body-cooler\cad\preview.png iso
```

几何全部由 `helix_sleeve()` 一个函数算出，纯 Python + 手写二进制 STL，**不依赖任何第三方库**。
核心参数：`r_in` `r_out` `slit` `pitch` `length` `ang_n` `step`。

## 自检

```
.venv\Scripts\python.exe .\projects\body-cooler\cad\_check.py
```

会打印螺旋缝的实际角间隙、弧长、壁厚，确认模型没错
（当前：缝 2.00mm / 壁厚 1.70mm / 外径 12.0 / 内径 8.6）。

Blender 导入后的网格检查结果：**NON_MANIFOLD 0，OPEN 0** —— 是水密实体，可直接切片。

## 生成方式说明

本机装的是 Blender 5.2.1（E:\Blender）。MCP 服务没法在会话中途热加载进工具表，
所以这里用的是 Blender 自带的 headless Python API：

```
blender.exe --background --factory-startup --python <脚本> -- <参数>
```

它比 MCP 更适合这件事 —— 参数化、可批量化、可版本控制，而且渲染预览和网格检查都能自动跑。

---

# 转角导弯件（`make_bends.py`）

上面那个螺旋护套是**直的**：转角处还得靠它自己弯，反复弯会疲劳开裂。
所以转角改成**已经弯好的硬质导槽** —— 管子走进去就是弯的，根本不存在「折」的机会。

## 为什么这样就不折了

```
  俯视（零件平放在打印床上就是这个姿态）

        进 ──┐                        ┌── 出
              │                        │
              └───────  R = 25mm  ─────┘
                   ↑
              圆弧是【建模出来的】，不是把直管掰弯的

  剖面（垂直于管路方向）

           ┌──── 开口 6.8mm ────┐       <- 管子从上面按进去（硅胶是软的，挤一下就过）
         ╱                       ╲
        │    内孔 Ø8.6（管 Ø8）   │      <- 硬壳 360° 包住管壁，压不瘪
        │                         │
         ╲_______________________╱
         外径 Ø12，包住 255°
```

**和直护套的区别**：直护套是「套上去再弯」（材料一直在受弯应力）；
转角件是「本来就是弯的」（材料零应力）。

## 文件

| 文件 | 转角 | 中心半径 | 外形尺寸 (mm) | 三角形 | 用途 |
|---|---|---|---|---|---|
| `bend_180_R25.stl` | 180° | 25 mm | 62.0 × 46.0 × 9.7 | 10652 | ★ 蛇形回折（主力件） |
| `bend_90_R25.stl`  | 90°  | 25 mm | 46.0 × 46.0 × 9.7 | 6212 | 直角拐弯 |
| `bend_45_R25.stl`  | 45°  | 25 mm | 28.2 × 47.5 × 9.7 | 3992 | 小角度转向 |
| `bend_180_R18.stl` | 180° | 18 mm | 48.0 × 39.0 × 9.7 | 10652 | 更紧凑的蛇形（管距 36mm） |
| `straight_80.stl`  | 0° | — | 12.0 × 80.0 × 9.7 | 3992 | 直段，连接两个转角件 |

**管距** = 2 × 中心半径。R25 → 两道管相距 **50 mm**；R18 → **36 mm**。

所有件都是**开口导槽**：内孔 Ø8.6，顶部开口 6.8 mm（比管子细 1.2 mm，按进去能卡住）。
壁厚 1.7 mm，外径 Ø12。

## 打印

| 项 | 建议 |
|---|---|
| 摆放 | **平放**（圆弧在 XY 平面，开口朝上）—— **完全不需要支撑** |
| 材料 | **PETG**。这个件不受弯，PLA 也能用，但 PETG 更耐摔、耐晒 |
| 层高 / 壁厚 | 0.2 mm / 3 圈（1.2mm）就够 |
| 填充 | 15%，或者干脆 0（全靠壁） |
| 底边 | 件是平的，接触面够，一般不用 brim |

## 组装

```
  蛇形面板俯视（1 米管子 -> 3 道，250 x 100 mm）

   ┌── bend_180 ──┐                    ┌── bend_180 ──┐
   │              │                    │              │
   └──────────────┴────────────────────┴──────────────┘
      ↑ 直段（straight_80）可以接好几节
```

1. 先把所有件**按布局摆好**（不用固定，先比划）；
2. 把管子一段段按进导槽 —— 转角件先按，直段再连接；
3. 相邻件**对接**即可，接口缠一圈电工胶带；
4. 最后整块贴到身上：缝进网布背心 / 用宽弹力带绑 / 贴在开槽 EVA 垫上。

## 按 1 米管子算，要打几个

管长 = 道数 × 250 mm + (道数 − 1) × πR

| 方案 | 道数 | 面板尺寸 | 需要的管子 | 要打的件 |
|---|---|---|---|---|
| R25（管距 50mm） | 3 | 250 × 100 mm | 1000 mm | `bend_180_R25` × 2 + 直段若干 |
| R18（管距 36mm） | 3 | 250 × 72 mm  | 984 mm  | `bend_180_R18` × 2 + 直段若干 |

> 想要一块像样的背垫（250 × 250 mm）需要 **6 道**，也就是 **2 米管子**。
> 硅胶管很便宜，建议直接买 3 米。

## 改参数重新生成

```
# 生成 STL（Blender headless）
& 'E:\Blender\blender.exe' -b --factory-startup --python .\projects\body-cooler\cad\make_bends.py

# 渲染预览 + 网格自检
& 'E:\Blender\blender.exe' -b --factory-startup --python .\projects\body-cooler\cad\render_bends.py
```

`make_bends.py` 顶部四个常数控制全部几何：

| 常数 | 默认 | 含义 |
|---|---|---|
| `RI` | 4.3 | 内孔半径（管 Ø8 + 0.6 间隙） |
| `RO` | 6.0 | 外半径（Ø12） |
| `OPEN_W` | 6.8 | 顶部开口宽度（越小卡得越紧） |
| `N_PROF` | 36 | 剖面圆弧分段数（越大越圆，文件越大） |

`VARIANTS` 表决定生成哪些件（转角角度 / 中心半径 / 端部直段长度）。

## 自检

`render_bends.py` 会顺便跑网格检查，当前结果：

```
CHECK bend_180_R25     verts=5328   tris=10652  non_manifold=0 open=0
CHECK bend_90_R25      verts=3108   tris=6212   non_manifold=0 open=0
CHECK bend_45_R25      verts=1998   tris=3992   non_manifold=0 open=0
CHECK bend_180_R18     verts=5328   tris=10652  non_manifold=0 open=0
CHECK straight_80      verts=1998   tris=3992   non_manifold=0 open=0
```

全部是水密实体（0 非流形边、0 开放边），可直接切片。

尺寸复核（直接读 STL 二进制头，不依赖 Blender）：

```
.venv\Scripts\python.exe .\projects\body-cooler\cad\stl_bbox.py
```

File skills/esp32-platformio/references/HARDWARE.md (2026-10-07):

# 硬件与串口

## 找 COM 口

```powershell
# 最省事：列出所有串口名
[System.IO.Ports.SerialPort]::GetPortNames()

# 端口 -> 设备映射（WMI 被沙箱挡住时的替代方案）
Get-ItemProperty 'HKLM:\HARDWARE\DEVICEMAP\SERIALCOMM'
```

后者输出形如：

```
\Device\Serial0 : COM1
\Device\Serial2 : COM5
```

`Get-CimInstance Win32_PnPEntity` 和 `Win32_SerialPort` 在沙箱里会报
`拒绝访问 (0x80041003)`，用上面的注册表读法代替。

要拿「这个 COM 口是什么芯片」，读 USB 枚举注册表：

```powershell
Get-ChildItem 'HKLM:\SYSTEM\CurrentControlSet\Enum\USB' |
  Where-Object PSChildName -match '1A86|303A|10C4' |
  Select-Object -ExpandProperty PSChildName
```

更完整的一条（拿到友好名，直接带 COM 号）：

```powershell
Get-ChildItem 'HKLM:\SYSTEM\CurrentControlSet\Enum\USB\VID_1A86&PID_55D3' | ForEach-Object {
  $p = Get-ItemProperty $_.PSPath
  "{0}  ->  {1}" -f $_.PSChildName, $p.FriendlyName
}
```

## 常见 USB 转串口芯片对照

| VID / PID | 芯片 | 说明 |
|---|---|---|
| `1A86 / 55D3` | **CH343** | 本板使用；WCH 高速 UART 桥 |
| `1A86 / 7523` | CH340 | 最常见的廉价桥 |
| `1A86 / 55D4` | CH9102 | CH340 的替代 |
| `10C4 / EA60` | CP2102 | Silicon Labs |
| `303A / 1001` | **ESP32-S3 原生 USB** | USB-Serial-JTAG 外设，不是 UART 桥 |

**本机实况**：`USB-Enhanced-SERIAL CH343 (COM5)` —— ESP32-S3 通过 **UART 桥**连接。

### 原生 USB 与 UART 桥的区别（很重要）

| | UART 桥（本板 CH343） | 原生 USB（`303A`） |
|---|---|---|
| 下载通道 | UART0，靠 DTR/RTS 自动复位 | USB-Serial-JTAG 外设 |
| 板定义 hwids 能否匹配 | **不能**（板定义写的是 `303A/1001`） | 能 |
| 固件 `Serial` 输出 | 直接就是 UART0，开箱即用 | 需 `ARDUINO_USB_CDC_ON_BOOT=1` |
| 上传参数 | 必须显式 `--upload-port` | 可自动识别 |

所以本板 `build_flags` 里是 `-DARDUINO_USB_CDC_ON_BOOT=0`。

## 复位 / 进下载模式

自动复位电路：**RTS → EN（复位）**，**DTR → GPIO0（启动模式）**。esptool 会自动组合这两根线；
进不去就手动 **按住 BOOT → 点 RST → 松 BOOT**。

用 pyserial 主动复位（`serial_capture.py --reset` 就是这么做的）：

```python
ser.setDTR(False)
ser.setRTS(True)      # 拉低 EN = 复位
time.sleep(0.12)
ser.setRTS(False)     # 松开 = 运行
time.sleep(0.05)
```

## 板载 LED

ESP32-S3-DevKitC-1 的板载 WS2812 RGB LED：

| 板版本 | GPIO |
|---|---|
| v1.1 | **48** |
| v1.0 | 38 |

`projects/hello-s3` 默认 `-DLED_PIN=48`（在 `build_flags` 里改）。
它是 **WS2812 可寻址灯**，不是普通 LED：`digitalWrite` 只能亮/灭/闪，
要颜色得用 `neopixelWrite(pin, r, g, b)` 或 Adafruit_NeoPixel 库。
第三方克隆板的 LED 引脚可能完全不同，不亮属正常。

## 用 esptool 独立确认板子身份

不确定手上是什么板时，只读信息不烧录：

```powershell
.\.venv\Scripts\python.exe .\.platformio\packages\tool-esptoolpy\esptool.py --port COM5 --no-stub flash_id
```

日志里 `Embedded PSRAM 8MB (AP_3v3)` 这一条就是判断 PSRAM 有无的唯一依据。

## 波特率

| 用途 | 值 |
|---|---|
| 应用串口输出（`Serial.begin()`） | 115200 |
| pio 监视器 `monitor_speed` | 115200 |
| 上传 `upload_speed` | 921600（不稳就降到 115200 / 460800） |

`upload_speed` 和 `monitor_speed` 是**两回事**：前者是烧录时临时协商的高速率，
后者是你读日志用的。

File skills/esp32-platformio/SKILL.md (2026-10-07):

---
name: esp32-platformio
description: 用 PlatformIO 开发 ESP32 / ESP32-S3 固件。自包含工作区（项目内 venv + 本地 PlatformIO core dir）、platformio.ini 配置（含 ESP32-S3-N16R8 的 16MB QIO flash + 8MB OPI PSRAM 双重开关）、编译/上传/串口抓取、CH343 串口桥与 COM 口识别、沙箱与代理环境适配、编译上传故障排查。
whenToUse: 用户要新建/编译/上传/调试 ESP32 系列固件（尤其 ESP32-S3-N16R8），要改 platformio.ini、配置 PSRAM 或 flash 分区、串口看不到输出、上传失败、或要求"把程序烧进板子/让板子跑起来"时使用。
---

# ESP32 开发（PlatformIO）

本技能把「写代码 → 编译 → 烧录 → 看串口」这条链路固定下来。工作区在
`D:\dsh_Workspaces\ESP32`，**自包含**：Python venv、PlatformIO core dir、临时目录全部在项目内，
不往用户目录写任何东西，删掉文件夹即彻底卸载。

## 环境事实（已在本机实测）

| 项目 | 值 |
|---|---|
| 工作区 | `D:\dsh_Workspaces\ESP32` |
| 启动器 | `scripts\pio.ps1`（唯一入口，自动设好所有环境变量） |
| Python | 3.14.7（`.venv`，venv 用 `--without-pip` 创建后打补丁） |
| PlatformIO Core | 6.2.0 |
| 平台 | `espressif32@7.1.3` → arduino-esp32 **2.0.17**（ESP-IDF 4.4.7，xtensa GCC 8.4） |
| 串口桥 | CH343（VID `1A86` PID `55D3`）→ **COM5** |
| 目标板 | ESP32-S3 (QFN56) rev v0.2，**16 MB flash + 8 MB OPI PSRAM** |
| 工程目录 | `projects\` |

## 快速上手

所有命令都从工作区根目录执行；`-d` 必须写在子命令**后面**。

```powershell
# 编译（默认环境 esp32-s3-n16r8）
.\scripts\pio.ps1 run -d .\projects\hello-s3

# 编译 + 烧录（串口必须显式给，见下文「上传口」）
.\scripts\pio.ps1 run -d .\projects\hello-s3 -t upload --upload-port COM5

# 看串口（不要用 pio device monitor，见下文）
.\.venv\Scripts\python.exe .\scripts\serial_capture.py --port COM5 --seconds 10

# 清干净重来
.\scripts\pio.ps1 run -d .\projects\hello-s3 -t clean
```

产物在 `projects\<名>\.pio\build\<env>\firmware.bin`（和 `firmware.elf`）。

## 五个必须知道的坑

### 1. 不要用 pio device monitor（脚本 / agent 环境里）

pio device monitor 要求 stdin 是交互式终端，在管道、CI 或 agent 环境里会直接报错：

```
UserSideException: requires an interactive terminal on stdin
```

改用技能自带的 `scripts/serial_capture.py`（pyserial 直接读口，可指定时长、可断言关键字）：

```powershell
.\.venv\Scripts\python.exe .\scripts\serial_capture.py --port COM5 --seconds 10 --reset
.\.venv\Scripts\python.exe .\scripts\serial_capture.py --port COM5 --seconds 5 --expect "boot OK"
```

### 2. 上传口必须显式指定

板子通过板载 **CH343 UART 桥**连接，不是 ESP32-S3 原生 USB。而 `esp32-s3-devkitc-1`
板定义里的 `hwids` 是 `0x303A/0x1001`（Espressif 原生 USB），**匹配不到 CH343**，
自动选口可能失败或选错。永远显式写 `--upload-port COM5`。

### 3. PowerShell 包装脚本不能有 param() 块

`scripts/pio.ps1` 故意**不声明 param()**。一旦声明，PowerShell 会把
`-e` / `-t` / `-v` 当成自己的参数名去绑定并报错，pio 根本收不到。
无 param 块时所有参数原样进 `$args`，再用 `@args` 透传。

### 4. PSRAM 需要两个开关，缺一不可

`board_build.arduino.memory_type = qio_opi` 只负责选对预编译 SDK 库；
Arduino 内核还会因为 `esp32-hal-psram.h` 里这段把 PSRAM 整个编译掉：

```c
#ifndef BOARD_HAS_PSRAM
#undef CONFIG_SPIRAM
#endif
```

**所以必须再加 `-DBOARD_HAS_PSRAM`**。漏掉它的症状极具迷惑性：固件正常启动、
串口一切正常，只有 `ESP.getPsramSize()` 返回 0。

### 5. 依赖下载走代理（否则慢 14 倍）

`dl.registry.platformio.org` 在本机直连只有 **~17 kB/s**，走本地代理
（`127.0.0.1:7897`）是 **~248 kB/s**。代理地址写在 `.pio-proxy` 里，
`pio.ps1` 会探测端口可达性后自动启用；端口不通则自动回退直连。
首次装平台约 700 MB，务必确认代理生效。

## 新建工程

```powershell
.\scripts\new_project.ps1 -Name my-app -Template s3-n16r8
cd projects\my-app
..\..\scripts\pio.ps1 run
```

可选模板：`s3-n16r8`（默认）、`s3-generic`、`esp32-classic`。
`projects\hello-s3` 是参考实现，可直接复制改写。

## 改 platformio.ini 的套路

```ini
[platformio]
default_envs = esp32-s3-n16r8      ; 不然 pio run 会把所有 env 都编一遍

[env:esp32-s3-n16r8]
platform  = espressif32
board     = esp32-s3-devkitc-1     ; 通用 S3 板定义，N16R8 靠下面几行覆盖
framework = arduino

board_build.mcu                 = esp32s3
board_build.flash_mode          = qio
board_build.arduino.memory_type = qio_opi     ; 16MB QIO flash + 8MB OPI PSRAM
board_upload.flash_size         = 16MB
board_build.partitions          = default_16MB.csv
build_flags = -DBOARD_HAS_PSRAM               ; 见坑 4

monitor_speed = 115200
upload_speed  = 921600
```

完整字段说明、其它板子模板、分区表选择见 `references/PLATFORMIO_INI.md`。

## 怎么确认真的成了

串口打印里必须有这三行（`projects/hello-s3` 的 `main.cpp` 会逐项自检）：

```
flash size      : 16 MB
psram           : 8386279 bytes total, 8386035 bytes free
[ OK ] 1 MB PSRAM read/write test passed
```

esptool 烧录日志里还会有 `Features: WiFi, BLE, Embedded PSRAM 8MB (AP_3v3)`，
这是判断"这块板到底是不是 N16R8"最可靠的依据。

## 故障排查

遇到报错先查 `references/TROUBLESHOOTING.md`，覆盖：找不到串口 / 上传超时 /
Failed to connect / PSRAM 为 0 / flash 容量不对 / 分区表放不下 /
`pio run` 参数不识别 / 下载卡住 / 沙箱 PermissionError / 串口乱码。

## 硬件细节

COM 口识别（WMI 被沙箱挡住时用注册表）、复位时序、板载 RGB LED 引脚、
原生 USB 与 UART 桥的区别，见 `references/HARDWARE.md`。

## 文件清单（本技能 bundle）

```
SKILL.md
references/PLATFORMIO_INI.md     配置字段、memory_type 取值、分区表、其它板子模板
references/TROUBLESHOOTING.md    症状 -> 原因 -> 修复 速查表（带实测踩坑）
references/HARDWARE.md           COM 口识别、CH343、复位时序、板载 LED、波特率
scripts/serial_capture.py        非交互串口抓取，可直接当断言用
scripts/new_project.ps1          按模板新建工程（模板内嵌在脚本里）
scripts/pio.ps1                  工作区 pio 入口的副本
scripts/dsh_sandbox_shim.py      沙箱补丁的副本
```

工作区的 `pio.ps1` / `env.ps1` / `bootstrap.ps1` 住在
`D:\dsh_Workspaces\ESP32\scripts\`，跟环境一起走。`scripts\` 下那两份副本
只是为了让技能 bundle 单独拿出来也能读，改的时候记得同步。

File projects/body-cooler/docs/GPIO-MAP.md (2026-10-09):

# GPIO 映射表（ESP32-S3 DevKitC-1 / N16R8）

工程里 `include/config.h` 的引脚定义跟这张表是一一对应的，改线一定要两边一起改。

---

## 一、总表

`rev1` = 现在这版固件已经烧录验证过的接线；`rev2` = 升级目标。
**rev2 是 rev1 的纯超集 —— 不移动任何已有引脚**，所以升级不用拆线，只是多接几根。

| GPIO | rev1 | rev2 | 方向 | 接线要点 |
|---|---|---|---|---|
| 1 | — | 电池电压 (ADC1_CH0) | 模拟输入 | 分压 100k / 18k，R2 上并 100nF |
| 2 | — | 备用模拟 (ADC1_CH1) | 模拟输入 | 泵电流 / 压力，暂空 |
| 3 | 禁用 | 禁用 | — | JTAG 源选择 strapping |
| 4 | DS18B20 总线 ×5 | 同左 | 双向 | 4.7k 上拉到 **3V3** |
| 5 | 继电器1 水泵 | 同左 | 输出 | 上电必须为不触发电平 |
| 6 | 继电器2 | 同左 | 输出 | 备用 / 风扇 |
| 7 | 继电器3 | 同左 | 输出 | 备用 |
| 8 | — | I2C SDA | 双向 | OLED / INA219 / SHT30 |
| 9 | — | I2C SCL | 输出 | 4.7k 上拉到 3V3 |
| 10 | — | 水流传感器 | 输入 / 中断 | 信号要 10k+15k 分压到 3.0V |
| 11 | — | 液位开关 | 输入 | 内部上拉，另一端接 GND |
| 12 | — | 空闲 | — | |
| 13 | — | 空闲 | — | |
| 14 | — | 空闲 | — | |
| 15 | 继电器4 | 同左 | 输出 | 备用 |
| 16 | 继电器5 | 同左 | 输出 | 备用 / 主电源总闸 |
| 17 | 蜂鸣器 | 同左 | 输出 | 有源蜂鸣器，可选 |
| 18 | 漏水检测 | 同左 | 输入 | 内部上拉，默认关闭 |
| 19 | 禁用 | 禁用 | — | 原生 USB D- |
| 20 | 禁用 | 禁用 | — | 原生 USB D+ |
| 21 | — | 总电源开关检测（可选） | 输入 | 内部上拉；不用可空着 |
| 26~32 | 禁用 | 禁用 | — | 内部 SPI flash |
| 33~37 | 禁用 | 禁用 | — | **OPI PSRAM**（用了就丢 8MB） |
| 38 | — | 按键 A | 输入 | 模式切换 / 配网 |
| 39 | — | 按键 B | 输入 | 手动强制降温 |
| 40 | — | 空闲 | — | |
| 41 | — | 空闲 | — | |
| 42 | — | 空闲 | — | |
| 43 | UART0 TX | 同左 | — | 板载 CH343 串口桥 |
| 44 | UART0 RX | 同左 | — | 保留给控制台 |
| 45 / 46 | 禁用 | 禁用 | — | strapping |
| 47 | — | 空闲 | — | |
| 48 | WS2812 状态灯 | 同左 | 输出 | 板载彩灯 |

**统计**：可用引脚 25 个（1 2 4 5 6 7 8 9 10 11 12 13 14 15 16 17 18 21 38 39 40 41 42 47 48）
rev2 已用 18 个，**还剩 7 个空闲**（12 13 14 40 41 42 47）。

---

## 二、按功能分组

### 输出（继电器 / 指示灯 / 蜂鸣器）

本项目实测：**继电器模块是低电平触发（L）** —— 把 IN 短接到 GND 就吸合。
`config.h` 里 `RELAY_ACTIVE_HIGH = 0`，并且默认用**开漏驱动**（`relay od`）。

| GPIO | 功能 | 吸合电平 | 释放电平 |
|---|---|---|---|
| 5 | 继电器1 → 365 水泵 | LOW (0V) | **高阻**（由 10k 上拉到模块 5V） |
| 6 | 继电器2 → 备用 | LOW | 高阻 |
| 7 | 继电器3 → 备用 | LOW | 高阻 |
| 15 | 继电器4 → 备用 | LOW | 高阻 |
| 16 | 继电器5 → 备用 / 总闸 | LOW | 高阻 |
| 17 | 蜂鸣器 | HIGH | LOW |
| 48 | WS2812 状态灯 | — | 灭 |

**为什么释放时必须高阻、不能推 3.3V**：模块 VCC 是 5V，光耦 LED 的阴极接在 IN 上。
IN 停在 3.3V 时 LED 上还有 5 − 3.3 − 1.2 ≈ 0.5V 的压差，微弱电流足以把继电器维持住，
表现就是「固件说 pump=OFF，泵却一直转」。引脚高阻时 LED 没有回路，才彻底截止。

固件里 `PumpController::begin()` 的顺序是**先写电平、再切成 OUTPUT**，
避免 `pinMode` 和 `digitalWrite` 之间那几微秒继电器误触发。
但复位到 `begin()` 之间固件管不到，所以 **IN 的 10k 上拉到模块 5V 是必须的**。

> 触发电平可以在运行时用串口切换：`relay high` / `relay low` / `relay od` / `relay pp`，
> 会存进 NVS，不用重新编译。想实测模块极性用 `relay test`（每 5 秒翻一次 IN，用耳朵听）。

### 输入（数字开关量）

| GPIO | 功能 | 上拉 | 有效电平 |
|---|---|---|---|
| 11 | 液位开关（浮子簧片） | 内部上拉 | 低 = 有水（`LEVEL_ACTIVE_LOW`） |
| 18 | 漏水检测（两根裸铜线） | 内部上拉 | 低 = 遇水（`LEAK_ACTIVE_LOW`） |
| 21 | 急停按钮（常闭 NC） | 内部上拉 | **高 = 按下或线断**（`ESTOP_ACTIVE_HIGH`） |
| 38 / 39 | 按键 A / B | 内部上拉 | 低 = 按下 |
| 10 | 水流传感器（霍尔脉冲） | 外部 10k 分压 | 下降沿计数 |

> GPIO21 原本留给急停按钮。现在**不需要独立的急停按钮**，
> 只要有一个**不解背包就够得着的总电源开关**（建议装在肩带上的自锁翘板开关）。
> 想用软件读开关状态也行；不用就把 `ENABLE_ESTOP` 保持 0，引脚空着。

### 输入（模拟 / ADC）

| GPIO | ADC 通道 | 用途 | 分压比 |
|---|---|---|---|
| 1 | ADC1_CH0 | 电池电压 | 6.556 : 1（100k / 18k） |
| 2 | ADC1_CH1 | 备用（泵电流 / 压力） | 待定 |

### 通信

| GPIO | 功能 |
|---|---|
| 8 / 9 | I2C SDA / SCL（OLED、INA219、SHT30） |
| 43 / 44 | UART0 → 板载 CH343 → 电脑 COM 口 |
| 19 / 20 | 预留：ESP32-S3 原生 USB（当前不用） |

---

## 三、为什么这些脚不能用

| GPIO | 原因 | 接上去会怎样 |
|---|---|---|
| 0 | strapping：上电电平决定 boot 模式 | 接负载 -> 烧录失败 / 启动异常 |
| 3 | strapping：JTAG 源选择 | 同上，且默认电压是 1.5V |
| 45 | strapping：VDD_SPI 电压选择 | 上电拉低 -> flash 供电错误，直接不启动 |
| 46 | strapping：启动模式 | 同上 |
| 19 / 20 | 原生 USB D- / D+ | 接负载 -> USB 通信异常 |
| 26 ~ 32 | 内部 SPI0/1，接 flash | **直接不启动** |
| 33 ~ 37 | OPI PSRAM（N16R8 才有） | 丢 8MB PSRAM，或直接不启动 |
| 43 / 44 | UART0 | 丢掉串口控制台（板载 CH343 就靠它） |

---

## 四、ADC 的两个大坑

### 1. ESP32-S3 有两组 ADC，WiFi 开启时 ADC2 不能用

| 组 | 引脚 | 备注 |
|---|---|---|
| **ADC1** | GPIO 1 ~ 10（CH0 ~ CH9） | 任何情况下都能用 |
| ADC2 | GPIO 11 ~ 20 | **WiFi 一开就不可用**（被射频占用） |

所以电池采样和泵电流采样**必须落在 GPIO1 ~ 10 上**。虽然现在没开 WiFi，
但升级路线里有手机端曲线这一项，先把线接对省得以后返工。

### 2. 源阻抗不能高

100k / 18k 分压的并联阻抗是 100k × 18k / 118k ≈ 15.3k，对 ESP32 的 ADC 来说偏高，
采样时会因为内部采样电容充电不足而读数偏低。两个办法，一起用最稳：

1. 在 R2 两端并一只 **100nF** 陶瓷电容 —— 给采样电容提供一个本地电荷池；
2. 用 `analogReadMilliVolts()` 而不是 `analogRead()` —— 它会读 eFuse 里的出厂校准值，
   比 `analogRead() * 3.3 / 4095` 准得多（固件里已经这么写了）。

顺带把衰减设成 11dB（`ADC_11db`），量程约 0 ~ 2.5V 线性段。
12.6V 经 6.556:1 分压是 1.92V，留了足够余量。

---

## 五、rev2 新增部分的接线图

### 电池电压（GPIO1）

```
  电池 BAT+ 12.6V
       |
     [R1 100k]
       |
       +------ GPIO1 (ADC1_CH0)
       |
     [R2 18k]      || 100nF
       |           ||
      GND         GND

  分压比 = (100 + 18) / 18 = 6.556
  12.6V -> 1.92V   9.0V -> 1.37V   0V -> 0V
```

静态耗电 12.6V / 118k ≈ 107uA，对 9Ah 的电池组可以忽略（约 0.001% / 小时）。

### 水流传感器（GPIO10）

```
  5V --- 传感器 VCC(红)
  GND -- 传感器 GND(黑)

  5V ---[2.2k]---+--- 传感器 OUT(黄)
                 |
               [10k] R1
                 |
                 +-------- GPIO10
                 |
               [20k] R2
                 |
                GND

  GPIO 高电平 = 5 * R2 / (Rpu + R1 + R2) = 5 * 20 / (2.2 + 10 + 20) = 3.11V
```

> **这一步不能省。** YF 系列水流传感器是 5V 供电、输出 5V 方波，
> ESP32-S3 的 IO **不是 5V 耐受**的（绝对最大 VDD + 0.3 = 3.6V）。
> 直连轻则引脚读数异常，重则烧脚。
>
> **那只 2.2k 也不能省。** 分压电阻本身就是个负载，会把高电平往下拽：
>
> | 上拉情况 | 送到 GPIO 的高电平 | 结果 |
> |---|---|---|
> | 自加 2.2k + 10k/20k | 3.11 V | 稳 |
> | 自加 4.7k + 10k/20k | 2.88 V | 可用 |
> | 只有传感器内部 10k + 10k/20k | 2.50 V | 贴着门限，危险 |
> | 只有传感器内部 10k + 10k/15k | 2.14 V | **低于门限，完全认不出高电平** |
>
> ESP32-S3 的输入高电平门限是 V_IH = 0.75 x 3.3 = **2.475V**。
> 接好后用万用表实测 GPIO10 对 GND 的高电平，**要在 2.8V 以上**。

### 液位开关（GPIO11）

```
  GPIO11 (内部上拉) --- 浮子开关 --- GND

  浮子抬起（有水）-> 闭合 -> 读低 -> levelOk = true
```

装在罐底上方约 10mm。注意选**常开（NO）**型，且用耐水的两芯线。

### 急停按钮（GPIO21）

```
  GPIO21 (内部上拉) --- 常闭按钮 --- GND

  不按  -> 闭合 -> 读低 -> 正常
  按下或线断 -> 断开 -> 读高 -> 急停（锁存，需 clear 复位）

  强烈建议同时把按钮的另一组触点串在泵的 12V 回路里：
    电池+ --- 保险丝 --- [急停常闭触点] --- 继电器 COM
  这样即使单片机死机，按下去也能硬切断。
```

### 漏水检测（GPIO18）

```
  GPIO18 (内部上拉) --- 裸铜线 A --- (2~3mm 间隙) --- 裸铜线 B --- GND

  两根线铺在背包底部（电池盒外围一圈）。遇水导通 -> 读低 -> 立即停泵 + 报警。
  不要镀锡：锡会钝化，久了就不导电了。用裸铜或镀金排针。
```

### I2C 总线（GPIO8 / GPIO9）

```
  3V3 ---[4.7k]---+---[4.7k]--- 3V3
                  |
  GPIO8 (SDA) ----+---- SDA(OLED / INA219)
  GPIO9 (SCL) ---------- SCL

  一条总线最多挂 8 个设备，OLED 和 INA219 地址不冲突，可以并联。
```

---

## 六、三块 ESP32-S3 怎么分工

| 板子 | 角色 | 说明 |
|---|---|---|
| A | **主控** | 跑本工程，负责控温、安全联锁 |
| B | **显示 / 网关**（可选） | 通过 UART 或 ESP-NOW 收 A 的数据，驱动 OLED、跑 BLE 手机端 |
| C | 备件 / 开发 | 烧坏了有得换 |

把无线功能放到 B 板是有原因的：WiFi 工作时约 100mA 且射频部分会发热，
挂在一个本身就要散热的装备上属于负收益。主控保持纯净，B 板可以塞在包里或者外接充电宝。

---

## 七、改引脚时要同步改的地方

1. `include/config.h` 里的 `#define PIN_xxx`
2. 本文档的表格
3. `docs/WIRING-REVIEW.md` 的接线图
4. 烧录后跑一遍 `scan` / `inputs` / `batt` / `flow`，确认读数和接的线对得上

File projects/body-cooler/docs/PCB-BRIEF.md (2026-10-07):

# PCB 设计规格书 —— body-cooler 全身降温器主控板

> **用途**：交给硬件工程师设计 PCB 的完整输入。
> **固件**：已完成并验证，引脚分配不可随意更改（见第 6 节）。
> **日期**：随固件版本同步更新。

---

# 1. 项目概述

背包式全身降温器。冰袋 + 水装在 PET 罐里，通过 **365 微型隔膜泵**把冷水打进贴在身上的 **8×11 软管**循环，
用 **DS18B20 温度探头**测水温和体表温度，**ESP32-S3** 通过**继电器**控制泵的间歇启停实现控温。

**核心约束（决定了整个设计）**：

| 约束 | 原因 |
|---|---|
| **泵不能用 PWM 调速** | 有刷电机换向器在 PWM 下剧烈打火；隔膜泵低速时阀片拍打异常。只能整段启停 |
| **控温靠时间比例** | 开关周期几十秒~几分钟，远大于电机热时间常数 |
| **电池背在身上** | 和水路在同一背包里，安全设计优先级最高 |
| **高湿 + 振动环境** | 冷凝水、身体晃动、软管拉扯 |

---

# 2. 系统框图

```
  ┌──────────────┐
  │ 3S 锂电池组   │ 9.0V(空) ~ 12.6V(满)，带 BMS
  └───────┬──────┘
          │
     ┌────▼─────┐
     │ 5A 快熔   │  ← 【必须有】
     └────┬─────┘
          │  +12V 母线
     ┌────┴───────────────┬──────────────────┐
     │                    │                  │
 ┌───▼────────┐    ┌──────▼──────┐    ┌──────▼──────┐
 │ 总电源开关   │    │ 12V→5V 降压  │    │ 12V→5V 降压  │
 │ (肩带/板上)  │    │   ≥3A  ← 路A │    │   ≥3A  ← 路B │
 └───┬────────┘    └──────┬──────┘    └──────┬──────┘
     │                    │ 5V_A             │ 5V_B
 ┌───▼──────┐        ┌────▼───────┐    ┌─────▼──────────┐
 │ 继电器组  │        │ 继电器线圈  │    │ ESP32-S3       │
 │  COM/NO  │        │  + 光耦     │    │ + 探头 + 传感器 │
 └───┬──────┘        └────────────┘    └─────┬──────────┘
     │ NO                                    │
 ┌───▼──────┐                          ┌─────▼──────────┐
 │ 365 水泵  │◄── 续流二极管并联        │ DS18B20 ×5     │
 │ 12V 450mA│                          │ 电池分压        │
 └───┬──────┘                          │ 水流/液位/漏水   │
     │                                 │ OLED (可选)     │
     └──────────────► 电池负 ───────────┴────────────────┘
```

## 2.1 电流路径铁律（这条踩过坑，烧过泵和电源板）

```
✅ 唯一正确的泵电流路径：
   电池+ → 保险丝 → 继电器 COM → NO → 泵+ → 泵− → 电池−

❌ 绝对禁止：
   泵的电流经过任何降压板 / 电源模块 / 稳压器
   泵的负极经过信号地或控制板 GND 铜箔
```

**原因**：泵启动瞬间 2A（额定 450mA 的 4~5 倍），且是感性负载。
曾经因为把泵接在 12V 降压板的输出上、且没有保险丝、没有续流二极管，
结果**泵和电源板同时烧毁**。

---

# 3. 电气总规格

| 项目 | 值 |
|---|---|
| 输入电压 | 9.0 V（3S 放空）~ 12.6 V（3S 满电） |
| 输入保护 | **5A 快熔保险丝**（板载或座子） |
| 主负载 | 365 隔膜泵，12V / 450mA，启动峰值 ~2A，感性 |
| 5V 轨总电流 | ESP32 ~120mA + 5 路继电器模块 ~425mA（全吸合）≈ **550mA**，峰值 700mA |
| 3.3V 轨 | 由 ESP32 模组/开发板上的 LDO 产生，**板上不要另做 3.3V 供 MCU 主电** |
| 工作温度 | 5 ~ 45 ℃（贴近皮肤 + 冷凝水环境） |
| 工作湿度 | 高湿，**必须做三防漆** |

## 3.1 电源树与电流预算

| 轨 | 来源 | 负载 | 稳态 | 峰值 | 建议能力 |
|---|---|---|---|---|---|
| +12V | 电池（经保险丝） | 泵 | 450 mA | **2 A** | 走线 ≥2A，自己一条 |
| +12V | 同上 | 5V 降压 ×2 | 0 | — | |
| 5V_A | 降压路A | 5 路继电器线圈 + 光耦 | 425 mA | 500 mA | **≥2 A** |
| 5V_B | 降压路B | ESP32 + 探头 + 传感器 | 120 mA | 200 mA | **≥1 A** |
| 3V3 | ESP32 板载 LDO | DS18B20 ×5 + I2C 上拉 | 10 mA | 50 mA | — |

**为什么两路 5V**：泵启停会在 12V 母线上产生尖峰，经降压器耦合到 5V。
共用一路时表现为 **ESP32 随机复位**。分路后 ESP32 拿到的是干净电源。

---

# 4. 板上必须实现的电路（PCB 设计要点）

## 4.1 泵驱动回路

**方案 A（推荐，沿用现有模块思路）**：板载 5V 继电器 + 驱动

```
                    ┌──────────────────┐
  +12V ──[F1 5A]────┤ COM              │
                    │  继电器 K1        ├─── NO ──┬──── 泵+
  GPIO5 ──[R 10k↑5V]┤ IN    线圈+ ──5V  │         │
                    │       线圈− ──GND │      ┌──┴──┐
                    └──────────────────┘      │ D1  │  1N5822
                                              │ 反向 │  阴极(有环)朝 +12V
  泵− ─────────────────────────────────────────┴──┴──┘
```

**必须有的三个元件**：

| 元件 | 参数 | 作用 | 位置要求 |
|---|---|---|---|
| **F1 保险丝** | 5A 快熔，5×20mm 或插片 | 短路保护 | 电池正极入口，**分流之前** |
| **D1 续流二极管** | 1N5822（3A/40V 肖特基）DO-201AD | 电机反峰泄放 | **紧靠泵接线端子** |
| **继电器线圈续流二极管** | 1N4148 或 1N4007 | 线圈反峰 | 紧靠线圈 |

**可选但强烈建议**：
- 继电器触点两端并联 **RC 吸收**（100Ω + 100nF/630V）或 TVS，进一步压电弧
- 泵端子并联 **100nF 陶瓷 + 100µF 电解**

**方案 B（更优，如果愿意改固件）**：
用 **N 沟道 MOSFET 低边开关**（如 IRLZ44N / IRF3205）代替机械继电器。

| | 机械继电器 | MOSFET |
|---|---|---|
| 寿命 | ~10 万次 | 无限 |
| 电弧 | 有 | 无 |
| 噪音 | 咔哒 | 静音 |
| 隔离 | 有 | 无 |

**但注意**：换 MOSFET 后**最短启停时间仍然要保留**（保护泵的阀片，与开关器件无关）。

## 4.2 5V 降压

| 项 | 要求 |
|---|---|
| 输入 | 9 ~ 12.6 V |
| 输出 | 5.0 V ±3% |
| 电流 | 每路 ≥2 A（推荐 5A 余量） |
| 效率 | ≥85%（电池供电，效率直接影响续航） |
| 推荐芯片 | **MP1584EN**（3A，90%）/ **XL4015**（5A）/ **TPS5450** / **MP2315** |
| 不推荐 | LM2596（效率 75%，静态 10mA） |

**每路输入必须**：470µF/25V 电解 + 100nF 陶瓷，**紧靠降压芯片输入脚**。

## 4.3 继电器输入电平（低电平触发）

```
  5V ──[R1 10k]──┬── 继电器模块 IN
                 │
  GPIO5 ─────────┘
```

**R1 是必须的**：模块是低电平触发，ESP32 复位期间 GPIO 高阻，
IN 悬空时可能被干扰误触发。**10k 上拉到 5V 保证不吸合**。

> 如果 PCB 上直接集成继电器驱动电路（不用成品模块），则设计成：
> 光耦输入侧 LED 阳极接 3V3（**不是 5V**），阴极经 1k 电阻接 GPIO。
> 这样 ESP32 输出低电平 = 光耦导通 = 继电器吸合，且天然 3.3V 兼容。

## 4.4 DS18B20 单总线

```
  3V3 ──[R 4.7k]──┬──────────────── GPIO4
                  │
              DS18B20 ×5 全部并联（DQ）
                  │
                 GND
```

| 要点 | 说明 |
|---|---|
| 上拉阻值 | **4.7k，整条总线只允许 1 个** |
| 上拉电压 | **必须 3V3，绝不能接 5V**（ESP32-S3 IO 不是 5V 耐受） |
| 探头数量 | 5 个并联（2 个水温 + 2 个体表 + 1 个环境） |
| 线长 | 探头引线可达 1~2m，**建议用屏蔽线，屏蔽层单端接 GND** |
| 若线很长（>5m） | 上拉改 2.2k |
| 接口 | 建议 3-pin JST-XH 2.54 或 2.54 排针 |

## 4.5 电池电压采样

```
  BAT+ 12.6V ──[R1 100k 1%]──┬── GPIO1（ADC1_CH0）
                             │
                          [R2 18k 1%]  ‖ C 100nF
                             │
                            GND
```

| 要点 | 说明 |
|---|---|
| 分压比 | (100+18)/18 = **6.556**，12.6V → 1.92V |
| 精度 | **1% 金属膜电阻**，否则读数偏 2~3% |
| 滤波 | R2 上并 **100nF**（降低对 ADC 的源阻抗） |
| **必须用 ADC1** | ESP32-S3 的 **ADC2（GPIO11~20）在 WiFi 开启时不可用** |
| 静态耗电 | 12.6V / 118k ≈ 107 µA（可忽略） |

## 4.6 水流传感器接口（可选）

```
  5V ──[R 2.2k]──┬── 传感器 OUT（黄线）
                 │
               [R 10k]
                 │
                 ├──────── GPIO10
                 │
               [R 20k]
                 │
                GND
```

**3 个电阻一个都不能省**。GPIO 上的高电平 = `5×20/(2.2+10+20)` = **3.11V**。
如果省掉 2.2k，高电平只有 2.14V，**低于 ESP32-S3 的 V_IH = 2.475V，识别不到**。

## 4.7 开关量输入

| 信号 | 接法 | 有效电平 |
|---|---|---|
| 液位开关（浮子常开） | 引脚 — 开关 — GND | 低 = 有水 |
| 漏水检测 | 引脚 — 裸铜线A ≈2mm — 裸铜线B — GND | 低 = 遇水 |
| 总电源开关检测 | 引脚 — 开关 — GND | 低 = 闭合 |
| 按键 A / B | 引脚 — 轻触开关 — GND | 低 = 按下 |

**全部用 MCU 内部上拉即可，不需要外部电阻。**
但**建议 PCB 上预留 10k 上拉焊盘**（内部上拉约 45k，噪声环境下偏弱）。

## 4.8 保护与滤波（汇总）

| 位置 | 元件 | 作用 |
|---|---|---|
| 电池入口 | 5A 快熔 | 短路保护 |
| 5V 降压输入 | 470µF + 100nF | 吸收泵启停浪涌 |
| 5V 降压输出 | 100µF + 100nF | 稳定 5V 轨 |
| 继电器模块 5V | 100µF | 线圈吸合瞬时电流 |
| 泵端子 | 续流二极管 + 100nF | 反峰泄放 |
| 12V 输入（可选） | SMBJ15A TVS + SS34 反接保护 | 浪涌 / 接反 |

---

# 5. 连接器清单（建议）

| 编号 | 用途 | 建议型号 | 位数 | 电流 |
|---|---|---|---|---|
| J1 | 电池输入 | **XT30** 或 KF301-2P | 2 | 5 A |
| J2 | 泵输出 | KF301-2P 或 XT30 | 2 | 3 A |
| J3 | DS18B20 总线 | JST-XH 2.54 3P | 3 | 0.5 A |
| J4 | 水流传感器 | JST-XH 2.54 3P | 3 | 0.5 A |
| J5 | 液位开关 | JST-XH 2.54 2P | 2 | 0.5 A |
| J6 | 漏水检测 | JST-XH 2.54 2P | 2 | 0.5 A |
| J7 | OLED (I2C) | JST-XH 2.54 4P | 4 | 0.2 A |
| J8 | 5 路继电器 | KF301 或 XH2.54 | 按下表 | 0.5 A |
| J9 | 调试串口 | 2.54 4P 排针（3V3/TX/RX/GND） | 4 | — |

### 继电器接口定义

| 继电器 | 控制侧 | 触点侧 |
|---|---|---|
| K1（泵） | VCC/GND/IN ← 5V_A, GPIO5 | COM ← +12V, NO → 泵+ |
| K2 | ← 5V_A, GPIO6 | 备用 |
| K3 | ← 5V_A, GPIO7 | 备用 |
| K4 | ← 5V_A, GPIO15 | 备用 |
| K5 | ← 5V_A, GPIO16 | 备用 |

---

# 6. MCU 引脚分配（**固件已固定，不可更改**）

主控：**ESP32-S3-DevKitC-1（N16R8，16MB flash + 8MB OPI PSRAM）**
若做核心板，用 **ESP32-S3-WROOM-1-N16R8** 模组。

| GPIO | 方向 | 功能 | 外围电路 | 固件开关 |
|---|---|---|---|---|
| **4** | 双向 | DS18B20 单总线 ×5 | 4.7k 上拉到 3V3 | 常开 |
| **5** | 输出 | 继电器 1（水泵）IN | 10k 上拉到 5V | 常开 |
| 6 | 输出 | 继电器 2 IN | 同上 | 常开 |
| 7 | 输出 | 继电器 3 IN | 同上 | 常开 |
| 15 | 输出 | 继电器 4 IN | 同上 | 常开 |
| 16 | 输出 | 继电器 5 IN | 同上 | 常开 |
| 17 | 输出 | 蜂鸣器 | 有源蜂鸣器，可选 | 常开 |
| 1 | 模拟输入 | 电池电压（ADC1_CH0） | 100k/18k 分压 + 100nF | `ENABLE_BATT_SENSE` |
| 2 | 模拟输入 | 备用（ADC1_CH1） | 预留 | — |
| 8 | 双向 | I2C SDA | 4.7k 上拉到 3V3 | `ENABLE_I2C` |
| 9 | 输出 | I2C SCL | 4.7k 上拉到 3V3 | 同上 |
| 10 | 输入/中断 | 水流传感器 | 2.2k 上拉 + 10k/20k 分压 | `ENABLE_FLOW_SENSOR` |
| 11 | 输入 | 液位开关 | 内部上拉（预留 10k 焊盘） | `ENABLE_LEVEL_SWITCH` |
| 18 | 输入 | 漏水检测 | 内部上拉（预留 10k 焊盘） | `ENABLE_LEAK_SENSOR` |
| 21 | 输入 | 总电源开关检测 | 内部上拉 | `ENABLE_ESTOP` |
| 38 | 输入 | 按键 A | 内部上拉 + 轻触开关到 GND | 待实现 |
| 39 | 输入 | 按键 B | 同上 | 待实现 |
| 48 | 输出 | 板载 WS2812 状态灯 | 板上自带 | 常开 |

## 6.1 绝对禁用的引脚

| GPIO | 原因 |
|---|---|
| **0 / 45 / 46** | strapping，上电电平决定启动模式，接负载会烧录失败或不启动 |
| **3** | strapping（JTAG 源选择） |
| **19 / 20** | 原生 USB D- / D+ |
| **26 ~ 32** | 内部 SPI flash |
| **33 ~ 37** | **OPI PSRAM**（N16R8 专有，占用了就丢 8MB PSRAM） |
| **43 / 44** | UART0，接板载 CH343 串口桥 |

## 6.2 可用引脚（共 25 个）

```
1  2  4  5  6  7  8  9  10 11 12 13 14 15 16 17 18 21 38 39 40 41 42 47 48
```

已用 18 个，**剩余 7 个**：`12 13 14 40 41 42 47`

---

# 7. 布局与机械要求

## 7.1 布局

| 要求 | 说明 |
|---|---|
| **功率回路最小** | 电池 → 保险丝 → 继电器 → 泵 的走线尽量短、够粗（≥1.5mm 线宽或铺铜） |
| **单点共地** | 5V_A 地、5V_B 地、3V3 地在电池负极处汇合，不要形成地环路 |
| **单总线远离功率线** | DS18B20 走线不要和泵电源线平行走 |
| **续流二极管紧靠泵端子** | 引线越短越好 |
| **滤波电容紧靠芯片** | 470µF 靠降压芯片输入脚 |
| **继电器远离单总线** | 触点电弧产生宽带干扰 |

## 7.2 机械

| 项 | 要求 |
|---|---|
| 板尺寸 | 建议 **100 × 60 mm** 以内，装进 IP65 防水盒 |
| 安装孔 | **M3 ×4**，四角，孔径 3.2mm |
| 板厚 | 1.6 mm |
| 连接器朝向 | 电源/泵接插件朝一侧，传感器朝另一侧 |
| 三防漆 | **必须**（高湿 + 冷凝水环境） |

## 7.3 环境

| 项 | 值 |
|---|---|
| 温度 | 5 ~ 45 ℃ |
| 湿度 | 高湿，可能凝露 |
| 振动 | 持续（行走），需要防松（螺钉胶 / 卡扣） |
| 防水 | 板子本身不防水，装在防水盒内 |

---

# 8. 调试与测试点（务必预留）

| 测试点 | 信号 |
|---|---|
| TP1 | +12V（保险丝后） |
| TP2 | +12V（保险丝前） |
| TP3 | 5V_A |
| TP4 | 5V_B |
| TP5 | 3V3 |
| TP6 | GND |
| TP7 | GPIO5（继电器 IN） |
| TP8 | DS18B20 DQ |

另外建议预留：
- **UART 调试排针**（3V3 / TX / RX / GND）
- **BOOT 按钮**（GPIO0 → GND）
- **RESET 按钮**（EN → GND）
- **串口下载电路**（CH343P 或直接引 USB 到原生口）

---

# 9. 血泪教训（设计时逐条核对）

| # | 教训 | 对应设计措施 |
|---|---|---|
| 1 | **泵从降压板取电，泵和降压板一起烧了** | 泵必须直接从电池经保险丝和继电器取电，走独立的粗铜线 |
| 2 | **没装保险丝** | 保险丝是第一优先级，不能省 |
| 3 | **没装续流二极管** | 泵两端必须反向并联 1N5822，紧靠端子 |
| 4 | **继电器是低电平触发** | IN 必须 10k 上拉到 5V，否则复位期间可能误吸合 |
| 5 | **ESP32 复位期间 GPIO 高阻** | 所有功率控制脚都要外部上拉/下拉定死默认状态 |
| 6 | **板子上有两个 USB 口** | 固件 Serial 走 UART0（CH343），插错口看不到日志。PCB 上直接标注清楚 |
| 7 | **ADC2 在 WiFi 下不可用** | 模拟采样只能放 GPIO1~10 |
| 8 | **OPI PSRAM 占用 GPIO33~37** | 不要引出这些脚 |
| 9 | **3.3V 逻辑驱动 5V 继电器模块** | 高电平只有 3.3V，压差 1.7V，光耦电流偏小。**PCB 上优先做 3.3V 原生驱动电路** |
| 10 | **泵不能 PWM** | 板上**不要**为泵预留 PWM 驱动电路 |

---

# 10. 建议的板载改进（相比现在的模块搭建）

| 改进 | 收益 |
|---|---|
| **继电器换成板载光耦 + MOSFET 低边开关** | 静音、无触点磨损、体积小。保留续流二极管 |
| **5V 降压集成到板上**（MP1584EN 或 TPS5450） | 省掉两个模块，走线短 |
| **板载 3S 电池电量计**（如 MAX17048） | 比电阻分压准 |
| **电流检测**（INA226 + 0.1Ω 分流） | 能测泵的实际电流，判断堵转/老化 |
| **TVS + 反接保护** | 减少接线事故 |
| **所有传感器用带扣连接器**（JST-XH/PH） | 振动环境下不会松（杜邦线会松） |
| **OLED 直接焊板上** | 不用单独模块 |

---

# 11. 固件配套信息

| 项 | 值 |
|---|---|
| 框架 | PlatformIO + Arduino-ESP32 2.0.17（ESP-IDF 4.4.7） |
| 板定义 | `esp32-s3-devkitc-1` + N16R8 覆盖（qio_opi / 16MB） |
| 串口 | **115200**，UART0（GPIO43/44） |
| 烧录 | esptool，921600 |
| 当前工作模式 | 台架测试（30 秒开 / 30 秒停），可通过 `mode 0` 切回正常控温 |

**如果 PCB 上改了任何引脚，需要同步修改 `include/config.h` 并重新编译。**

---

# 12. 一句话给画板的朋友

> 这是一块**电池供电、要背在人身上、驱动一台 12V 感性负载电机、还要接 5 路继电器和 5 个温度探头**的
> ESP32-S3 控制板。**电源完整性和保护电路是重点，不是 MCU 部分。**
> 特别是：泵的电流路径只能有 保险丝 + 继电器触点 两个东西，
> 续流二极管和滤波电容必须紧靠负载和芯片，
> 而 3.3V 的 GPIO 不能直接驱动 5V 的继电器模块输入（要高电平上拉或做 3.3V 原生驱动）。

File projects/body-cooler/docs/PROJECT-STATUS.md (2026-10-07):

# 项目当前状态（PROJECT STATUS）

> 快照时间：本文件随每次改动更新。位置：`D:\dsh_Workspaces\ESP32\projects\body-cooler`

---

# 一、一句话现状

**固件已完成并烧录进板子，当前运行在「台架测试模式」（30 秒开泵 / 30 秒停泵）。**
温度探头还没接，所以还没有进入真正的控温。

---

# 二、已完成的部分

## 2.1 硬件方案

| 子系统 | 方案 | 状态 |
|---|---|---|
| 冷源 | 冰袋 + 水，装在 PET 罐里 | 人工装填，无电控 |
| 循环 | 365 泵，间歇启停（**不能 PWM**） | 固件已实现 |
| 散热 | 8×11 软管贴身循环 | 待组装 |
| 控温 | DS18B20 ×5（水温进出 + 体表胸背 + 环境） | **待接线** |
| 主控 | ESP32-S3 DevKitC-1 | ✅ 已跑通 |
| 开关 | 5V 光耦继电器模块 ×5 | ✅ 已接线测试 |
| 电源 | 3S 锂电 → DC-DC → 5V | 待确认模块电流能力 |

## 2.2 固件功能清单

| 功能 | 位置 | 状态 |
|---|---|---|
| DS18B20 ×5 异步采集 + ROM 角色映射 | `src/tempsensor.cpp` | ✅ |
| 回差 / 时间比例 / **台架测试** 三种模式 | `src/controller.cpp` | ✅ |
| 三层保护（安全联锁 / 最短启停 / 需求判定） | `src/controller.cpp` | ✅ |
| 电池电压采样（未接线自识别） | `src/inputs.cpp` | ✅ 代码就绪，默认关闭 |
| 水流传感器（中断计数 + 标定） | `src/inputs.cpp` | ✅ 代码就绪，默认关闭 |
| 液位 / 漏水 / 总电源开关检测 | `src/inputs.cpp` | ✅ 代码就绪，默认关闭 |
| 串口 CLI（40+ 命令） | `src/console.cpp` | ✅ |
| NVS 持久化（角色 / 设定 / 统计） | 各模块 | ✅ |
| WS2812 状态灯 + 蜂鸣器 | `src/main.cpp` | ✅ |

**编译状态**：RAM 6.1% / Flash 5.0%，无 error 无 warning。
**烧录状态**：已烧入板子（串口 COM6，115200）。

## 2.3 引脚分配

| GPIO | 功能 |
|---|---|
| 4 | DS18B20 单总线 ×5（4.7k 上拉到 **3V3**） |
| 5 / 6 / 7 / 15 / 16 | 继电器 1~5 的 IN |
| 17 | 蜂鸣器（可选） |
| 18 | 漏水检测（可选） |
| 1 | 电池电压 ADC1（可选） |
| 8 / 9 | I2C（OLED 等，可选） |
| 10 | 水流传感器（可选） |
| 11 | 液位开关（可选） |
| 21 | 总电源开关检测（可选） |
| 38 / 39 | 按键 A/B（可选） |
| 48 | 板载 WS2812 状态灯 |

**禁用**：0 / 3 / 45 / 46（strapping）、19 / 20（USB）、26~32（flash）、33~37（OPI PSRAM）、43 / 44（串口）。

详细映射见 `docs/GPIO-MAP.md`。

## 2.4 文档清单

| 文件 | 内容 |
|---|---|
| `README.md` | 项目总览、快速开始、命令表 |
| `wiring.html` | ★ 交互式实物接线图（阳极客风网页） |
| `docs/BENCH-TEST.md` | ★ **台架测试：现在这个口接那个口** |
| `docs/PROJECT-STATUS.md` | 本文件 |
| `docs/WIRING-GUIDE.md` | 接线总览与电路原理 |
| `docs/GPIO-MAP.md` | 完整 GPIO 映射表 |
| `docs/BOM.md` | 采购清单（型号 + 搜索词 + 避坑） |
| `docs/ORDER-REVIEW.md` | 京东订单核对（买错什么、还要补什么） |
| `docs/BRINGUP.md` | 7 步桌面测试流程 |
| `docs/UPGRADE-PLAN.md` | 分阶段升级方案 P0~P4 |
| `docs/WIRING-REVIEW.md` | 接线与电源审查（6 处必须改） |
| `docs/SEALING-REVIEW.md` | 密封、冷凝与热工审查 |
| `docs/diagrams/*.png` | 6 张工程图纸 |

---

# 三、还没做的

## 3.1 卡脖子的（不解决没法往下走）

| 项目 | 说明 |
|---|---|
| **DS18B20 防水探头 ×5** | 你买的是带 PCB 的「模块版」，不能泡水、不能贴皮肤，而且只有 3 个。**必须补买不锈钢封装的防水探头** |
| 5A 保险丝 + 座 | 电池正极出口必须有 |
| M12 硅胶 O 型圈 / 尼龙平垫 | 先拆穿板接头看是否自带 |

## 3.2 建议补的

| 项目 | 用途 |
|---|---|
| YF-S401 水流传感器 | 最可靠的干转 / 气堵检测 |
| M10 浮球液位开关 | 从根上防干转 |
| 肩带总电源开关 KCD1-101 | 不解背包就能断电 |
| 0.96 寸 OLED | 不背电脑就能看状态 |

## 3.3 机电部分

| 项目 | 状态 |
|---|---|
| PET 罐开孔 + 穿板接头密封 | 未开始 |
| 软管裁到 4~5m + 暴露段套保温管 | 未开始（保温管已到货 12mm×14mm，6m） |
| 背包分层 + 防水内衬 | 未开始 |
| 上身测试 | 未开始 |

---

# 四、关键设计决策（已定，别再纠结）

| 决策 | 原因 |
|---|---|
| **水泵只能整段启停，不能 PWM** | 有刷电机换向器在 PWM 下剧烈打火；隔膜泵低速阀片拍打异常 |
| **用时间比例模拟调速** | 周期几十秒到几分钟，远大于电机热时间常数 |
| **继电器用 NO 不用 NC** | 断电/死机/线断时泵自动停，失效安全 |
| **续流二极管必须有** | 感性负载反峰几百伏，会烧触点 + 打复位 ESP32 |
| **两路 DC-DC 分开** | 泵启动瞬间 2A，干扰会顺着电源进单片机 |
| **TEC 方案放弃** | 5 片 TEC1-12712 要 50A / 600W，热端 1300W 排不掉，电池撑 10 分钟 |
| **DS18B20 用 ROM 地址绑角色** | 总线上电顺序会变，按序号绑会串角色 |
| **整条单总线只加 1 个 4.7k 上拉** | 5 个模块各带一个就是 940Ω，太低 |
| **端子排方案放弃，改单个端子 + 直连** | 端子排是多余的一层接点 |

---

# 五、待确认的问题

1. **电池组是否自带 BMS 保护板？** 没有的话 3S 放到 9V 以下电芯永久损伤
2. **DC-DC 多路模块每路电流多少？** 5V 路要 ≥2A
3. **365 泵的电压档位**（标题里有 3V/4.5V/5V/6V/12V 多个 SKU）
4. **穿板接头包装里有没有自带螺母和密封圈**

---

# 六、下一步

```
现在  →  按 docs/BENCH-TEST.md 接继电器+泵+电池，跑 30/30 台架测试
        ↓  验证：继电器时序、泵转动、ESP32 不复位
探头到货  →  接 DS18B20 ×5，scan + map + save
        ↓  验证：5 个探头读数正确、冰水校准 0°C
机电做完  →  加水循环测密封，再做控温闭环测试
        ↓  最后才上身
```

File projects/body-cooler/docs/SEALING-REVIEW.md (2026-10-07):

# 密封、冷凝与热工审查

> 结论先说：**你的密封做法是对的**（穿板宝塔头 + 内外硅胶圈 + 卡箍 + 卡箍），
> 但有一个认知偏差需要纠正：
> 「把冰袋封在 PET 罐里就不会有冷凝水」—— 不完全对。冷凝水不会消失，
> 它只是**从冰袋表面转移到了罐外壁和 10 米长的低温软管外壁**。
> 而软管那一部分才是大头。

---

## 一、冷凝水：真正的问题在管子，不在罐子

冷量最终一定要和空气接触才能漏出去，有低温表面就一定有冷凝水。

| 部位 | 温度 | 面积 | 冷凝情况 |
|---|---|---|---|
| 冰袋表面 | -5 ~ 0 度 | 大 | 已经封在罐里，解决 |
| **PET 罐外壁** | 5 ~ 10 度 | 约 0.06 m2 | 会结露，顺着罐壁往下淌 |
| **10m 软管的暴露段** | 8 ~ 15 度 | 约 0.20 m2 | **主要问题** —— 6~7 米长的冷管子就是一台除湿机 |
| 软管的贴身段 | 25 ~ 30 度 | 约 0.15 m2 | 管壁被皮肤加热，基本不结露 |

**做法**：

1. **暴露段软管全部套保温海绵管**（空调铜管用的那种黑色闭孔橡塑发泡管，
   **内径 12mm**）。注意：8x11 管的意思是内径 8 / 外径 **11mm**，
   所以保温管内径必须 >= 12mm 才套得进去。这一步同时解决两件事：隔断结露 + 减少冷损，
   而冷损比结露更致命（见第四节）。
2. **PET 罐外面套保温套**（潜水料 / 珍珠棉 / 保温袋），再把罐子放进背包的**防水内衬**里，
   内衬底部留一个**朝下的排水小口**，万一渗水不会泡到电池。
3. **贴身段软管在速干衣下面**，那一段的少量冷凝水直接被衣服吸收。
4. 背包里不要放怕水的东西。电池盒单独做防水。

---

## 二、PET 罐开孔与密封（你的方案基本正确，补几个细节）

你说的是「穿板宝塔头（外径 8mm，螺纹 M12）× 5 + 硅胶密封圈 × 10 + 304 卡箍 × 10」，
**10 个圈 = 5 个接头 × 内外各 1 个，数量正好，这个搭配是对的**。下面是执行细节：

### 开孔

* **PET 又脆又薄，直接钻孔必裂**。步骤：
  1. 用 3mm 钻头打引导孔（防止钻头跑偏）；
  2. 换 **12mm 钻头**扩孔。穿板接头自带螺母 + 密封圈，**不需要攻丝** ——
     攻 M12 螺纹反而会把 PET 涨裂；
  3. **低转速 + 滴几滴水冷却**。转速高了 PET 会熔化拉丝，孔口变成一圈毛刺，密封圈压不实。
* 孔位要求：**离罐壁边缘 >= 8mm，离罐底 >= 10mm**。
* 5 个孔**分散布置**，不要全挤在同一侧 —— 受力不均会让薄壁罐变形，密封圈跟着失效。

### 密封圈装配顺序（内外各一个）

```
    罐外              罐壁            罐内
  [宝塔头法兰] [硅胶圈] │PET│ [硅胶圈] [螺母]
```

* 拧紧力度：**手拧到刚好吃住，再紧 1/4 圈**。用扳手暴力拧 = PET 开裂。
* **PET 会蠕变**：装好后 24 小时，以及第一次跑循环之后，**再复紧一次**。
  很多人第一次漏水都是因为漏了这一步。

### 软管与卡箍

* 软管要**插到宝塔头根部**，把所有台阶都淹没 —— 宝塔头的每一道凸起都是一道密封；
* 卡箍卡在**凸起之后**（靠近法兰那一侧的第一道台阶后方），**不要卡在凸起上面**，
  卡在凸起上会让软管鼓包，密封反而更差；
* 304 卡箍拧到「软管表面微微凹陷」就够，拧过头会切伤软管。

### 建议从盖子出管，而不是从侧壁

* 广口盒的**盖子平整、厚实、好开孔、好密封**，而且侧壁出管在背包里
  **容易被压弯折死**（流量归零，泵空转）。
* 代价：卡扣盖本身的密封靠一圈硅胶条，不算可靠。
  **内侧再贴一圈自粘硅胶密封条**，并且盖子周围用一根魔术贴绑带箍紧。

### 罐内必须留 15~20% 空气，并且强烈建议加透气口

* 这是**闭式循环**（出水和回水都在同一个罐上），净流量为零，理论上不会产生持续负压。
* **但是**：① 水温变化导致罐内空气热胀冷缩；② 泵启动 / 停止瞬间的压力波动；
  ③ 万一回水管有轻微渗漏进了空气。
  一个**完全刚性密封**的薄壁 PET 罐，在泵抽水时会被**吸瘪**。
* **做法**：在盖子上装一个 **防水透气阀**（Gore 阀 / 疏水透气膜），
  或者一根 30mm 短管 + 一小团棉花或海绵塞（防溅水）。

---

## ★ 软管被泵吸瘪（贴身段尤其明显）—— 排查与根治

**现象**：贴身段的软管在工作时被吸成扁的，流量掉下去，泵声音变尖（憋压）。

**先明白一件事：瘪 = 管子承受的负压 > 管壁的抗压能力。**
所以只有两条路：**要么别让这段管子处在负压侧，要么让管子抗得住。**
按性价比从高到低：

### ① 罐子必须透气（不花钱，先查这个）

如果罐子被完全密封，泵一抽就把罐内抽成负压 —— 那时**整个回路从头到尾都是负压**，
再硬的管子也可能瘪，而且泵会气蚀、流量暴跌。**先拧开盖子或者装透气阀试一次**，
如果瘪立刻减轻，就是这个问题。

### ② ★ 把泵挪到体表回路的上游：改成「推」，不要「吸」（根本解法，不花钱）

```
现在（吸）：罐 → 体表管 → 泵 → 罐      体表管全程负压  → 瘪
改成（推）：罐 → 泵 → 体表管 → 罐      体表管全程正压  → 不可能瘪
```

365 隔膜泵自吸能力够，两种接法都能工作，但**「推」对软管友好得多**——
正压只会让管子鼓，不会让它瘪。这就是为什么家用净水器、鱼缸过滤都是「泵在后、
负载在前」。

**顺带的好处**：最冷的那段水（刚从冰袋出来）直接进体表管，冷量损失更小。
**代价**：接头漏水会往衣服里喷水（负压时反而是往管内吸空气，更安全），
所以接头一定要卡箍拧紧。

### ③ 负压段别用硅胶管

| 管材 | 抗负压 | 说明 |
|---|---|---|
| PU / PE / PVC 硬管 | 强 | 8×11 那种，负压段随便用 |
| 硅胶管 6×8（壁厚 1mm） | **极弱** | 手感软，一吸就瘪 —— **只能用在泵的出口侧** |

贴身段想用硅胶图舒服，可以，但**必须放在泵的下游（正压侧）**。

### ④ 防瘪弹簧 / 螺旋增强管

* 把一根不锈钢丝绕成螺旋（外径略小于管内径）塞进软管里，就是最简单的防瘪内衬；
* 或者直接买**带螺旋筋的防瘪吸水管**（养鱼 / 洗车用的那种透明螺旋管）。
* 缺点：内壁有筋，阻力上升，流量会降一点。

### ⑤ 降低沿程阻力（负压 ∝ 阻力）

* **死折是最凶的**：一个 90° 死折的局部阻力相当于好几米直管，那一段一定最先瘪。
  所有拐弯半径做到 **> 5 倍管径**（8mm 管 -> 半径 > 40mm）。
* 负压段尽量短，别用比 8mm 更细的过渡接头（那等于一个限流孔）。
* 贴身段的盘管别盘得太密 —— 每一圈都是一个弯。

### ⑥ 排查手法

1. 关掉泵，用手把整条管路摸一遍，先找死折和压扁的地方；
2. 开泵，从泵的入口往回摸，**最先瘪的那一段就是阻力最大的地方**；
3. ⚠ **管子瘪着的时候泵处在憋压状态，长时间会把阀片顶坏 / 电机过热熔化** ——
   发现瘪立刻停机处理，别让它硬抽。

---

## ★ 贴身那 1 米软管怎么固定才不会被压瘪

**关键认知：圆截面的软管天生怕侧向点压力。** 只有两条思路 ——
**要么给它做「外骨骼」把点压变成面压，要么把这一段挪出负压侧。**

### 方案 D（零成本，最优先）：把这一米挪到泵的出口侧

正压侧的管子被压只会**鼓**，不会瘪。如果贴身段现在在泵的入口侧，
它天生就是「被吸瘪」的命 —— 先改管路，再谈固定。

```
罐 → 泵 → [这 1 米贴身管，正压] → 回罐        ← 就改成这样
```

### 方案 A（最推荐，DIY 一下午）：嵌进开槽泡棉，做成一块换热垫

```
俯视（贴皮肤的那一面）：
  ┌──────────────────────────────┐
  │  EVA 泡棉 5mm                 │
  │   ████████████████████████   │  <- 蛇形槽，宽 = 管外径 8mm
  │   ██ 硅胶管嵌在槽里 ██████   │     槽深 ≈ 管径的 2/3
  │  ──────────────────────────  │
  └──────────────────────────────┘
     ↑ 管子露出 1/3 直接贴皮肤换热，2/3 被泡棉保护
```

* 材料：5mm 厚 **EVA 泡棉**（瑜伽垫 / 鼠标垫 / 儿童地垫都行），裁成胸口或后背的形状；
* 用美工刀挖一条**蛇形槽**，槽宽 = 硅胶管外径（8mm），槽深约 5~6mm；
* 把硅胶管压进槽里 —— **垂直方向的所有压力都由泡棉承担**，管子被"包"住，压不瘪；
* 露出的 1/3 管壁照常贴皮肤换热，泡棉的隔热影响很小；
* 边缘缝两条宽松紧带 / 魔术贴，固定在速干衣外面。

### 方案 B：螺旋弹簧内衬（唯一能让软管本身抗瘪的办法）

* 不锈钢丝 **Φ0.8mm**，绕成螺旋，**外径约 5mm**（硅胶管内径 6mm，留 1mm 余量才能塞进去），
  螺距 3~5mm，整段穿进去；
* 或者直接买**「防瘪弹簧管」/「螺旋增强硅胶管」**；
* 代价：沿程阻力上升，流量降 10~20%。

### 方案 C：外套塑料波纹穿线管

硅胶管穿进**内径 8~10mm 的塑料波纹管**里。波纹管的环向刚性很高，压不瘪、还能弯。
代价：外径变粗到 14~16mm，贴身变硬变硌 —— 只适合走路，不适合背着靠。

### 方案 E（正确答案，但要花钱）：换成扁通道冷敷垫

圆管和皮肤只有**一条线**接触，换热效率本来就差。
医用冷敷垫那种**扁平多通道 PVC 垫**天生抗压（压力方向垂直于通道宽面），
而且换热面积大 4~5 倍。买不到就自己用两片 PVC/TPU 膜热合成蛇形通道。

### 方案 F：走位，避开所有受压点

* ✗ 别走**肩带正下方**、别走**脊柱正中**、别走**腰带位置**；
* ✓ 走**肩胛骨内侧的凹处**、贴着**肋骨**走；
* 用**宽扁的松紧带**分散固定，**别用细尼龙扎带勒** —— 细扎带本身就是一个压瘪点。

### 顺带说管材

6×8 硅胶管的**壁厚只有 1mm**，是抗瘪能力最差的规格。
如果一定要用软管贴身，选 **6×10（壁厚 2mm）** 会好很多，代价是粗一点、贴合差一点。

---

## ★★ 让泵不会因为被压瘪而死（三道防线，比机械固定更紧急）

你已经烧掉 2 台泵了。机械固定是「尽量不发生」，下面三道是「发生了也不会烧」。

| 防线 | 实现 | 代价 | 说明 |
|---|---|---|---|
| ① 水流传感器 | 装 **YF-S401** 到 GPIO10，`ENABLE_FLOW_SENSOR` 改 1 | 约 10 元 | **最灵**，能抓住「管子刚好被压瘪」那一瞬间 |
| ② 连续运行上限 | 串口 `maxrun <分钟>`，默认 10 分钟 | 0 元 | 不用传感器，兜底 |
| ③ **热保护开关** | **KSD9700 常闭 70°C** 串在泵的电源线上 | 几毛钱 | **硬件保护，最可靠** |

**防线③ 强烈建议装上。** 它是双金属片机械开关，泵壳一到 70°C 直接物理断电 ——
不管固件怎么错、MCU 怎么死机、MOS 怎么击穿，它都会断。这是最后一道保险，
而且只要有它在，前两道即使失效也不会烧泵。串接位置：

```
电池+ → 保险丝 → 继电器 COM → NO → [KSD9700 70°C] → 泵+ → 泵− → 电池−
                                     ↑ 紧贴泵壳，用导热硅脂+扎带固定
```

固件侧已实现（`controller.cpp` `updateRunGuard()`）：

* 判据①（需水流传感器）：泵开着但 `FLOW_CHECK_MS`(15s) 内流量 < `FLOW_MIN_LPM`(0.2 L/min)；
* 判据②：`m_curOnMs > maxRunMs`；
* 触发后：立即停泵 → 强制休息 `grest`（默认 60s）→ **自动重试**，形成「试-停-试」循环；
* `status` 的 `reason` 行会直接说明原因，例如：
  `泵保护停机：泵在转但水流传感器读不到水（管瘪 / 堵塞 / 没水）（42 秒后自动重试）`；
* `clear` 可立即解除，`maxrun 0` 可关闭（不建议）。

* **吸水管**（去泵的那根）伸到罐底，但**离底 5~10mm**，管口剪成斜口或套一个不锈钢网 / 海绵粗滤，
  防止吸到底部碎屑和冰袋碎渣。**这一条直接决定泵会不会堵。**
* **回水管**（从身上回来的）伸到罐内**液面附近**，不要插到底 ——
  避免回水直冲罐底搅动沉淀，也避免停机时虹吸倒流。

---

## 三、泵的安装位置

* 泵装在罐外，**进水口低于罐内最低液位**。利用重力灌注。
  365 泵虽然标称自吸，但自吸高度超过 0.3~0.5m 后流量会明显下降，而且容易气蚀、噪音大。
* 进水口管路**尽量短、少弯头**，中间不要用比 8mm 更细的过渡接头（那就是个限流孔）。
* **绝对不能干转**。隔膜泵干转几分钟，阀片和膜片就废了。
  第一次使用必须先灌引水（从回水管往罐里倒水，或者把回水管拔下来看有没有水出来）。
  固件里的 `DRY_RUN` 报警就是给这个兜底的。
* 泵和罐、泵和背包之间**垫一层减震海绵**。隔膜泵的振动在背包里会被放大成嗡嗡声，
  而且长期振动会磨破软管。

---

## 四、热工估算：这套系统到底能撑多久

这部分建议认真看一遍，因为它决定了你的预期是否合理。

### 10 米软管的代价

8mm 内径、10 米长：

```
管内容积 = 3.1416 x (4mm)^2 x 10000mm = 502,655 mm3 约等于 0.50 升
```

**你的水箱才 500ml —— 管路里的水和罐里的水一样多。** 后果：

* 泵要先把这 0.5L 的水推完一圈，才有冷量回到罐里，系统响应变慢；
* 这 0.5L 水本身也是热容，需要额外的冰去冷却它。

沿程阻力其实**没有想象中那么糟**：10 米 8mm 管在 1.5 L/min 下压降约 **6~7 kPa（0.06~0.07 bar）**，
对 365 泵（最大压力 0.2~0.5 MPa）来说只掉 10~20% 流量。**真正的代价是冷损，见下条。**

### 保温 vs 不保温：真实数字

按圆柱保温层算（管内水温 10C、环境 30C），每米冷损：

| 保温层厚度 | 成品外径 | 每米冷损 | 相比裸管 | 外表面温度 | 会不会结露 |
|---|---|---|---|---|---|
| 裸管 | 11 mm | **9.0 W/m** | — | 10 C | **必结露** |
| 9 mm | 30 mm | 6.2 W/m | -31% | 25.0 C | 临界（露点约 26 C） |
| **13 mm** | 38 mm | **5.5 W/m** | -39% | 26.6 C | 基本不结 |
| 20 mm | 52 mm | 4.6 W/m | -48% | 27.9 C | 不结 |

> 这里有个反直觉的地方：保温层加厚之后**外径也变大了**，
> 外表面积从 0.035 m2/m 涨到 0.119 m2/m（13mm 时），
> 加上辐射散热，**实际收益比直觉小**。9mm 只降 31%，20mm 才降 48%。
> 别指望套一层保温就能把冷损干掉 90%。

**更关键的是：裁短软管比套保温有效得多。**

| 配置 | 暴露段 | 软管冷损 | 罐壁冷损 | 总冷损 | 预计续航 | 其中有效冷却 |
|---|---|---|---|---|---|---|
| 10 m 管，不保温 | 6.5 m | 58 W | 12 W | **70 W** | 32 分钟 | 12 分钟当量 |
| 10 m 管 + 13mm 保温 | 6.5 m | 36 W | 2 W | 37 W | 46 分钟 | 24 分钟当量 |
| 5 m 管，不保温 | 2 m | 18 W | 12 W | 30 W | 51 分钟 | 29 分钟当量 |
| **5 m 管 + 13mm 保温** | 2 m | 11 W | 2 W | **13 W** | **67 分钟** | **51 分钟当量** |

假设：冰量 500 g（214 kJ）、体表吸热 40 W。

**结论**：

* 只套保温（管子还是 10m）：**有效冷却翻倍**（12 -> 24 分钟当量）
* 只裁管子（5m，不保温）：有效冷却 12 -> 29 分钟当量，**比只套保温还强**
* **两个一起做：有效冷却提升 4 倍以上**（12 -> 51 分钟当量）

所以正确顺序是：**先裁管子，再套保温。** 保温是雪中送炭之后再加的棉袄，
不是单独就能救命的。

### 但保温管还有一个不可替代的作用：防结露

这一条和冷损无关，是**独立且确凿**的理由：

* 裸露冷管外壁约 10 C，而 30 C / 80%RH 的露点约 **26.2 C**
  （湿度 90% 时露点升到 28.2 C）
* 温差 16 C，必然大量结露，水顺着管子滴到身上和背包里
* 套 13mm 保温后外表面升到 **26.6 C**，刚好压住露点

**你当初把冰袋封进 PET 罐就是为了防这个，但冷凝水只是转移到了罐外壁和管子外壁。**
想彻底解决，光靠保温不够，要三件套一起上：

1. 暴露段套 13mm 保温管
2. 罐子套保温套，放进背包的**防水内衬**里
3. 内衬底部留一个**朝下的排水小口**

**省钱省事的做法**：贴身那一段软管**根本不用保温** —— 它贴着皮肤，本来就是要换热的。
只有「从背包出来到衣服里」那一小段是暴露的。
把罐子和泵放在**背包最下层**，软管从背包底部直接穿进衣服，
暴露段可以压到 **1~1.5 m**，保温管只买 1.5 m 就够了，又省钱又不臃肿。

### 冰量能撑多久

按你现有的配置（500ml 水 + 自吸水冰袋）估算，假设有效冰量 **500g**：

```
融化潜热          334 J/g x 500 g          = 167 kJ
冰从 -5 度升到 0 度  2.05 J/(g·K) x 500 x 5  =   5 kJ
融水从 0 度升到 20 度 4.18 J/(g·K) x 500 x 20 =  42 kJ
                                    合计  约 214 kJ
```

* 静息状态（人体产热约 100W，系统实际带走约 40W）：
  **214 kJ / 40 W 约等于 5350 秒 约等于 89 分钟**
* 活动状态（产热 200~400W，系统带走 60W 左右，且冰消耗更快）：
  **大约 30~45 分钟**

**结论：这是一套「延缓升温 / 局部降温」装备，不是「全身空调」。**
要延长续航，按性价比排序：

1. **加保温**（效果最猛）—— 续航 x1.5~2
2. **加大水量**：100x150mm 的 PET 盒大概能装 1~1.5L，用 2~3 个盒子串联；
   水的显热虽然不如冰，但能显著延长最后那 20 分钟
3. **加冰量**：冰袋从 500g 加到 1kg —— 续航线性延长
4. **缩短软管**：从 10m 裁到 4~5m，减少管内容积和暴露面积

### 走管与人体安全

* **软管不能直接贴皮肤**（你已经知道）。再补充一点：8x11 的 PVC 管**偏硬**，
  长时间压在背上会形成压痕和压迫点。建议贴身段换 **6x8 的硅胶管**
  （更软、更细、更贴合），或者在外面包一层薄棉布做成垫片。
* **冷损伤**：水温低于 12 度左右、长时间大面积接触皮肤，有冷性荨麻疹和冻伤风险。
  所以固件里设了 `wmin`（默认 8 度停泵）。**建议实测后调到 10~12 度。**
* **走管避开**腋下、腹股沟、颈前这些大血管浅表区 —— 在这些地方快速降温会引起
  强烈不适甚至寒战（寒战反而会让产热暴增，适得其反）。
* **单次连续使用不超过 60 分钟**，中间让皮肤回暖。

---

## 五、密封测试怎么做（做完了再上身）

### 静态保压测试

1. 罐里装满水，**把所有接头拧紧**，堵住出水口和回水口。
2. 用手捏软管加压（或者用泵短时憋压 **不超过 10 秒** —— 憋太久会损坏泵的阀片）。
3. 罐子下面垫**干燥的纸巾**，静置 **30 分钟**。
4. 纸巾有任何湿痕 → 找到那个接头，复紧；还漏就换密封圈。

### 动态循环测试

1. 泵接上，装满水，让它**连续循环 30 分钟**。
2. 观察所有接头、罐底、泵的进出水口。
3. 中途把罐子**倒过来放 5 分钟**（模拟背包晃动），继续观察。
4. 注意听泵的声音：有明显咕噜咕噜的气泡声 → 进水口漏气，检查卡箍和宝塔头。

### 冷凝测试

1. 罐里放冰袋，泵循环起来，**在湿度大的环境**（比如刚洗完澡的浴室）放 20 分钟。
2. 看罐外壁和软管外壁有没有水珠往下滴。
3. 有 → 按第一节加保温棉和保温套。

---

## 六、一句话总结

| 你的原方案 | 评价 |
|---|---|
| 穿板宝塔头 + 内外硅胶圈 + 卡箍 | 正确，注意 24 小时后复紧，别暴力拧 |
| 冰袋密封在 PET 罐内 | 部分正确 —— 冰袋本身没问题了，但冷凝转移到了**罐外壁 + 10m 软管**，必须加保温 |
| 软管不直接贴皮肤、穿速干衣 | 正确，建议贴身段换更软的硅胶管 |
| 先桌面测试密封和电路再上身 | 完全正确，流程见 docs/BRINGUP.md |
| 500ml 水 + 10m 管 | 需注意 —— **管内容积约等于罐内容积**，建议裁到 4~5m |
| 没有提到保温 | **必须加**，不加等于续航砍半 |

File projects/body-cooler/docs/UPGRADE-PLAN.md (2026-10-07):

# 升级方案（v1 → v2）

> 引脚映射见 `docs/GPIO-MAP.md`。本文只讲**改什么、为什么、怎么验收**。

固件已经把 v2 的输入层写好了（`src/inputs.cpp`），
但所有新功能都由 `config.h` 里的 `ENABLE_xxx` 开关控制，**默认全部关闭** ——
因为没接线时引脚悬空会误报，板子会一直停在 FAULT。
接好一根线、验证过读数，再把对应的开关改成 1。

---

## 阶段总览

| 阶段 | 内容 | 成本 | 工作量 | 优先级 |
|---|---|---|---|---|
| **P0** | 安全与可靠性（二极管 / 上拉 / 保险丝 / 保温 / 急停 / 漏水） | 约 60 元 | 1 个晚上 | **必做** |
| **P1** | 传感器（电池 / 水流 / 液位 / OLED） | 约 70 元 | 2 个晚上 | 强烈建议 |
| **P2** | 结构与热工（保温全面化 / 加冰 / 减震 / 背包分层） | 约 80 元 | 1 个周末 | 收益最大 |
| **P3** | 软件与互联（手机端 / 记录 / 自适应控温） | 0 元 | 多个晚上 | 可选 |
| **P4** | TEC 方案 | 约 400 元 | 大量 | **不推荐，见后文算账** |

---

# P0 — 安全与可靠性（必做）

这一阶段不提升降温效果，但决定这套东西**能不能安全地背在身上**。

## P0-1 泵两端加续流二极管

* **物料**：1N5408（3A/1000V）或 SS34（肖特基）× 1，约 1 元
* **接法**：反向并联在泵的两个端子上，**阴极（有环的一端）接 +12V 侧**
* **为什么**：有刷电机是大电感，继电器断开瞬间的反峰可达几百伏。
  一是让触点拉弧、几个月后接触电阻变大（表现：继电器咔哒响但泵不转）；
  二是顺着 12V 母线回灌，通过 DC-DC 把 ESP32 打复位。
* **验收**：`mon 3` + `moff 3` 让泵每分钟启停一次，跑 30 分钟，串口不丢字符、板子不重启。
* **注意**：方向接反 = 直接把 12V 短路，会立刻烧保险丝。装之前用万用表二极管档确认方向。

## P0-2 继电器 IN 引脚的 10k 上拉 / 下拉

* **物料**：10kΩ 电阻 × 5，约 0.5 元
* **接法**：高电平触发模块 —— IN 到 GND 接 10k；低电平触发模块 —— IN 到 5V 接 10k
* **为什么**：ESP32 复位期间 GPIO 是高阻，IN 悬空。固件的「先写电平再切 OUTPUT」只覆盖
  `begin()` 之后，复位到 `begin()` 之间那几百毫秒只有外部电阻能兜住。
* **验收**：泵接上但不给水，反复按 RST 键 20 次（每次上电 2 秒），泵一次都不许抽。

## P0-3 双 DC-DC 分路 + 滤波电容

* **物料**：470uF/25V 电解 × 2、100nF 陶瓷 × 4、磁珠 × 1，约 10 元
* **接线**：DC-DC 1 只供泵和继电器模块；**DC-DC 2 只供 ESP32 和探头**；
  两条路在电池负极处单点共地。DC-DC 的 12V 输入并 470uF + 100nF，
  泵端子并 100nF + 100uF，继电器模块附近放 100uF。
* **为什么**：泵启动瞬间是额定电流的 3~5 倍（0.45A × 4 ≈ 2A），
  母线会塌陷 + 叠加尖峰。分路之后 ESP32 看到的电源干净得多。
* **验收**：同 P0-1。再加一条 —— 用手摸 ESP32 的 3V3，泵启停时不应该是明显的抖动。

## P0-4 保险丝 + 电池保护

* **物料**：5A 快熔保险丝 + 座 × 1（约 5 元）、3S BMS 保护板（约 12 元，电池组自带的就省了）
* **接法**：保险丝串在**电池正极出口、分流之前**
* **为什么**：锂电短路电流几十安，不保就是点焊机；3S 放到 9V 以下电芯永久损伤，
  而绝大多数 DC-DC 模块**没有欠压关断**，会一直抽到 6V。
* **注意**：3 个电池组**不要直接并联**（内阻不一致会环流）。一次用一个，轮换。

## P0-5 总电源开关（不一定需要 22mm 蘑菇头急停）

* **物料**：**肩带自锁翘板开关**（KCD1-101，2脚2档，>=10A）约 5 元；
  或 12mm 防水自锁按钮约 10 元。**22mm 蘑菇头是机柜件，戴在身上不合适。**

  > **为什么蘑菇头可以不要**：真正的问题不是「按钮大不大」，而是「够不够得着」。
  > 电源在背包里，靠「手快拔插头」等于要先把包摘下来。
  > 而且**不要用拔连接器当停机手段** —— 带载拔 XT30/XT60 会拉弧，插针几次就烧蚀。
  >
  > 另外修正我之前的说法：**任何串在泵回路里的开关，线断了都是断开 -> 泵停。**
  > 常闭（NC）的「失效安全」优势并不是独一份的，普通 SPST 开关一样成立。
  > 蘑菇头唯一独有的是「大、闭着眼能拍到」，这在背包上不重要。
* **接线**：
  * 软：GPIO21 —— 按钮 —— GND（内部上拉），`config.h` 里 `ENABLE_ESTOP` 改 1
  * 硬：**另一组触点串在泵的 12V 回路里** —— 电池+ → 保险丝 → 急停常闭 → 继电器 COM
* **为什么**：常闭接法下「按下」和「线断了」是同一种结果（引脚被上拉拉高），失效安全。
  软件急停依赖单片机活着，硬线急停不依赖 —— 两个都要有。
* **固件行为**：触发后**锁存**，泵立即停、LED 红闪、蜂鸣器报警；松开后要手动 `clear` 才恢复。
* **验收**：泵运行中按急停 → 泵立即停；松开 → 仍然停；`clear` → 恢复自动。
  然后拔掉按钮的一根线（模拟断线）→ 同样进入急停。

## P0-6 漏水检测

* **物料**：两根裸铜线（不要镀锡）× 2 根，约 0 元
* **接法**：GPIO18 —— 裸铜线 A ——（2~3mm 间隙）—— 裸铜线 B —— GND，`ENABLE_LEAK_SENSOR` 改 1
* **位置**：铺在背包底部，把电池盒外围一圈
* **为什么**：12V + 锂电池 + 水在同一个背包里，这是唯一可能真正出事的组合。
* **验收**：用湿纸巾同时碰两根线 → 泵立即停、LED 红闪、串口 `LEAK`。

## P0-7 保温（软管 + 罐体）

* **物料**：空调橡塑保温管 **内径 12mm x 壁厚 9mm** 约 2m（10 元）、
  罐体保温套 / 3mm 潜水料片材（10 元），合计约 20 元
  > 尺寸别买错：8x11 管的外径是 11mm，保温管内径 9mm 是套不进去的。
* **为什么**：两个作用。

  1. **防结露（不可替代）**：裸露冷管外壁 10 C，30 C / 80%RH 的露点 26.2 C，
     必然大量结露、滴水。13mm 保温把外表面抬到 26.6 C，刚好压住露点。
  2. **减冷损**：裸管 9.0 W/m -> 13mm 保温 5.5 W/m，降约 39%。
     注意保温层加厚后外径也变大，**收益比直觉小**，别指望降 90%。

  完整测算见 `docs/SEALING-REVIEW.md`。一句话结论：
  **裁短软管比套保温更有效，两个一起做有效冷却才能提升 4 倍。**
* **验收**：在湿度大的环境（刚洗完澡的浴室）跑 20 分钟，罐外壁和软管外壁不挂水珠。

---

# P1 — 传感器与闭环质量（强烈建议）

## P1-1 电池电压采样

* **物料**：100kΩ + 18kΩ 电阻、100nF 电容，约 1 元
* **接线**：见 `docs/GPIO-MAP.md` 第五节；`ENABLE_BATT_SENSE` 改 1
* **为什么**：现在完全不知道电池还剩多少。跑着跑着泵变慢（有刷电机转速正比于电压），
  然后突然掉电 —— 对背在身上的人来说很糟。加了之后可以：
  * `batt` 命令随时看电压
  * 低于 10.5V 报 `BATT_LOW`（3.5V/芯，该准备换电池）
  * 低于 9.6V 报 `BATT_CRIT` 并**强制停泵**保护电芯（带回差恢复）
* **固件的贴心处**：读数低于 6V 会被判定为「分压没接」而不是「电池坏了」——
  因为 ESP32 自己要从电池取电，能跑起来说明电池至少 7V。这样没接线时不会误报。
* **验收**：`batt` 读数与万用表量电池正负极的差值在 0.2V 以内。
  如果差得多，实际量一下两只电阻的阻值，把 `BATT_DIV_R1_KOHM` / `R2` 改成实测值。

## P1-2 水流传感器

* **物料**：YF-S401（0.3~6 L/min，5880 脉冲/升）约 25 元，或 YF-S201（1~30 L/min，450 脉冲/升）约 15 元
* **接线**：见 `docs/GPIO-MAP.md` 第五节，**信号线必须 10k/15k 分压**；`ENABLE_FLOW_SENSOR` 改 1
* **为什么**：这是**最可靠的干转 / 气堵 / 管路堵塞检测**，比现在靠温度的启发式判断准确得多。
  同时能算出真实制冷功率（`P = 流量 × 4.186 × 温差`），把 `flow` 从估算变成实测。
* **标定**：`flowcal 5880`（YF-S401）或 `flowcal 450`（YF-S201），然后 `savecfg` 持久化。
  更准的做法：用量杯接 1 升水，看 `flow` 的累计值对不对，按比例修正。
* **固件行为**：泵运行超过 15 秒而流量低于 0.2 L/min → 报 `NO_FLOW`。
* **验收**：泵跑起来 `flow` 显示 1~2 L/min；把进水口从水里提出来，15 秒内报 `NO_FLOW`。

## P1-3 液位开关

* **物料**：浮子簧片开关（常开型）约 5 元
* **接线**：GPIO11 —— 开关 —— GND（内部上拉），`ENABLE_LEVEL_SWITCH` 改 1
* **为什么**：从根上杜绝干转。隔膜泵干转几分钟，阀片和膜片就废了。
  装在罐底上方约 10mm。固件做了 3 次采样去抖（1.5 秒），防止背包晃动导致误判。
* **验收**：把开关从水里拿出来 → 15 秒内泵停 + 报 `LEVEL_LOW`；放回去自动恢复。

## P1-4 OLED 显示屏

* **物料**：0.96 寸 SSD1306 I2C OLED 约 15 元
* **接线**：GPIO8/9，一条 I2C 总线上还可以并 INA219（泵电流检测）和 SHT30（环境温湿度）
* **为什么**：不用背电脑就能看状态。建议 4 页轮播：
  1. 主界面：体表温度 / 目标 / 泵状态 / 剩余时间估算
  2. 水温：出水 / 回水 / 温差 / 制冷功率
  3. 电源：电池电压 / 本次运行时长 / 累计启停次数
  4. 诊断：所有探头读数 / 报警 / 各路输入引脚状态
* **工作量**：固件里还没有这部分，需要新写一个 `display.cpp`（约 200 行）。

## P1-5 软管裁短 + 贴身段换管

* **10 米裁到 4~5 米**：8mm 内径 10 米的容积是 0.50 升，**和水箱一样大**。
  裁短能减少管内容积、减少暴露面积、降低泵的负担。
* **贴身段换 6×8 硅胶管**：8×11 的 PVC 管偏硬，长时间压在背上会形成压痕和压迫点。
  硅胶管更软更贴合，而且导热比 PVC 好一点。
* 接回 8mm 主管用一个 8mm 变 6mm 的宝塔变径接头。

## P1-6 水箱扩容

* **零成本**：三个 PET 盒串联成 1.5L 水箱（进水管一个一个串过去），比单个 500ml 强很多。
* 水的显热虽然不如冰的潜热，但能把「最后那 20 分钟」显著拉长。

---

# P2 — 结构与热工（收益最大）

## P2-1 加冰量

按 500g 有效冰量估算，系统有效冷量约 214 kJ：

| 状态 | 500g 冰 | 1000g 冰 |
|---|---|---|
| 静息（带走约 40W） | 约 89 分钟 | 约 178 分钟 |
| 活动（带走约 60W） | 约 30~45 分钟 | 约 60~90 分钟 |

冰量是**线性**延长续航的，最直接。注意自吸水冰袋要冻透（-5C 以下），
半冻的冰袋潜热少一大半。

## P2-2 减震

* 泵和罐、泵和背包之间垫一层减震海绵（约 5 元）。
* 隔膜泵的振动在背包里会被放大成嗡嗡声，而且长期振动会磨破软管。
* 有条件的话把泵用魔术贴绑带固定在硬板上，再让硬板通过海绵接触背包。

## P2-3 背包分层

```
  最上层：电池防水盒（独立隔间，和水路之间加隔板）
  中间层：控制盒（ESP32 + DC-DC + 继电器）、PET 水箱 + 保温套
  最下层：泵、管路接口、漏水检测线
```

重力方向决定漏水只会往下走，电池在最上面就永远碰不到水。

## P2-4 风扇（继电器 3）

如果罐体保温做得好，风扇意义不大。但在**高湿度**环境下，
一个小风扇吹罐体表面能把结露吹干。用 `aux 2 on` 手动测试，或者以后写进固件。

---

# P3 — 软件与互联（可选）

| 项目 | 说明 | 工作量 |
|---|---|---|
| 手机端曲线 | 用第二块 S3 做 BLE 网关，手机看实时温度和电量 | 大 |
| 数据记录 | 运行数据存 NVS 环形缓冲，串口导出 CSV 做分析 | 中 |
| 自适应控温 | 根据降温速率（dT/dt）预测并提前停泵，减少温度过冲 | 中 |
| OTA 升级 | 不用每次插 USB | 中 |
| 环境自适应 | 加 SHT30 测环境温湿度，自动调整目标温度 | 小 |
| 能耗统计 | 用 INA219 记录泵的实际电流，估算剩余电量 | 小 |

> 提醒：WiFi 工作时约 100mA 且射频部分发热，挂在一个本身要散热的装备上是负收益。
> 所以把无线功能放到第二块板子上，主控保持纯净。

---

# P4 — TEC 方案：先算账再动手

你手上有 5 片 TEC1-12712。**在背包场景下它们基本用不了**，原因不是技术难度，是能量账：

```
单片 TEC1-12712 @12V：
  输入功率    约 120 W（10 A）
  制冷量      约 90 ~ 100 W（理想工况，Th = 27C）
  热端要排掉  约 210 ~ 220 W

5 片一起上：
  输入功率    约 600 W（50 A @ 12V）
  热端要排掉  约 1300 W
```

对比一下你的家底：

| 项目 | 现状 | TEC 需求 |
|---|---|---|
| 继电器 | 10 A / 路 | **50 A**，直接烧毁 |
| 电池 | 3S 18650，约 100 Wh | 600 W 只能撑 **10 分钟** |
| 散热 | 无 | 要排 1300 W，相当于一台小空调的冷凝器 |

**结论：5 片 TEC 不可行。** 就算只用 1 片，144W 的输入对现有电池组也只能撑 40 分钟，
而且热端的散热器 + 风扇的体积和噪音远超一整个冰袋方案 —— 续航还只有冰袋的三分之一。

半导体制冷对**可穿戴**场景是死路：它把热量从一边搬到另一边，但总热量只增不减，
而背包里既没有风道也没有空间把这部分热量排掉。

**这 5 片留着做别的**：给电池做低温保温、做台式恒温实验台、或者拆开当温差发电片玩。

---

# 固件路线图

## 已经实现（本工程当前版本）

| 功能 | 位置 |
|---|---|
| DS18B20 x5 异步采集 + ROM 角色映射 | `src/tempsensor.cpp` |
| 回差 / 时间比例双模式控温状态机 | `src/controller.cpp` |
| 安全联锁（过冷 / 无水 / 传感器失效 / 漏水 / 急停 / 低电 / 缺水 / 无水流） | `src/controller.cpp` |
| 最短启停时间保护（保护触点与泵阀片） | `src/controller.cpp` |
| 电池电压采样 + 未接线自识别 | `src/inputs.cpp` |
| 水流传感器（中断计数 + 标定 + 累计水量） | `src/inputs.cpp` |
| 液位开关 / 急停 / 漏水（带去抖与锁存） | `src/inputs.cpp` |
| 串口 CLI（40+ 命令）+ NVS 持久化 | `src/console.cpp` |
| WS2812 状态灯颜色编码 + 蜂鸣器报警 | `src/main.cpp` |
| 运行统计（累计时长 / 启停次数 / 10 分钟占空比） | `src/controller.cpp` |

## 还要写的

| 功能 | 建议位置 | 工作量 |
|---|---|---|
| OLED 显示驱动 + 4 页界面 | 新增 `src/display.cpp` | 约 200 行 |
| INA219 电流采样（泵堵转 / 老化检测） | 新增 `src/power.cpp` | 约 100 行 |
| 数据记录环形缓冲 + CSV 导出 | 新增 `src/logger.cpp` | 约 150 行 |
| BLE 手机端 | 新增 `src/ble.cpp`（放第二块板） | 约 300 行 |
| 自适应控温（速率预测） | `src/controller.cpp` | 约 80 行 |
| 按键 A / B 交互 | `src/main.cpp` | 约 60 行 |

---

> **具体型号、参数、搜索关键词、避坑清单见 `docs/BOM.md`。**

# 采购清单（按阶段汇总）

| 物料 | 数量 | 参考价 | 阶段 |
|---|---|---|---|
| 1N5408 二极管 | 2 | 2 元 | P0 |
| 10kΩ 电阻 | 10 | 1 元 | P0 |
| 470uF/25V 电解 + 100nF 陶瓷 | 各 5 | 10 元 | P0 |
| 5A 保险丝 + 座 | 1 | 5 元 | P0 |
| 3S BMS 保护板 | 1 | 12 元 | P0 |
| 常闭急停按钮 | 1 | 6 元 | P0 |
| 空调保温棉管（内径 10mm） | 2 m | 10 元 | P0 |
| 罐体保温套 / 潜水料 | 1 | 10 元 | P0 |
| **P0 小计** | | **约 56 元** | |
| 100kΩ + 18kΩ 精密电阻 | 各 2 | 1 元 | P1 |
| YF-S401 水流传感器 | 1 | 25 元 | P1 |
| 浮子液位开关 | 1 | 5 元 | P1 |
| 0.96 寸 OLED (SSD1306 I2C) | 1 | 15 元 | P1 |
| 6x8 硅胶管 | 5 m | 20 元 | P1 |
| **P1 小计** | | **约 66 元** | |
| 自吸水冰袋（补充） | 20 | 30 元 | P2 |
| 减震海绵 | 1 张 | 5 元 | P2 |
| 防水盒 / 隔板 | 2 | 30 元 | P2 |
| 宝塔变径接头 8mm→6mm | 2 | 10 元 | P2 |
| **P2 小计** | | **约 75 元** | |

**P0 + P1 + P2 一共约 200 元。** 其中 P0 和 P2 的收益最大，P1 提升的是可观测性。

---

# 建议的执行顺序

1. **先做 P0 全部** —— 在重新上身之前，这 7 项一项都不能省。
2. **P2-1 加冰 + P0-7 保温** 这两项一起做，续航预期直接翻倍。
3. **P1-2 水流传感器** —— 有了它，干转检测才真正可靠，可以放心把泵交给固件自动跑。
4. **P1-1 电池采样** —— 便宜且立竿见影，接上就知道还能撑多久。
5. 剩下的按兴趣慢慢来。

每一步做完都回 `docs/BRINGUP.md` 对应的小节做验收，别攒着一起测。

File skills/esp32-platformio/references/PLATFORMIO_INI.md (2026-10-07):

# platformio.ini 参考

## 三层配置，越靠下优先级越高

1. **platform 默认** — `.platformio\platforms\espressif32\` 里的脚本行为
2. **board 定义** — `.platformio\platforms\espressif32\boards\<board>.json`
3. **platformio.ini 的 `[env:*]`** — 你写的东西覆盖上面两层

`board = esp32-s3-devkitc-1` 的真实内容是（节选）：

```json
"build": {
  "arduino": { "ldscript": "esp32s3_out.ld", "partitions": "default_8MB.csv" },
  "extra_flags": ["-DARDUINO_ESP32S3_DEV", "-DARDUINO_USB_MODE=1"],
  "f_cpu": "240000000L", "flash_mode": "qio", "mcu": "esp32s3", "variant": "esp32s3"
},
"name": "Espressif ESP32-S3-DevKitC-1-N8 (8 MB QD, No PSRAM)",
"upload": { "flash_size": "8MB", "maximum_size": 8388608, "speed": 460800 }
```

注意它自称 **N8 / No PSRAM** —— N16R8 的一切都要靠 ini 覆盖。

## ESP32-S3-N16R8 完整模板

```ini
[platformio]
default_envs = esp32-s3-n16r8

[env:esp32-s3-n16r8]
platform  = espressif32
board     = esp32-s3-devkitc-1
framework = arduino

; --- 模块差异（N16R8 靠这 5 行覆盖 N8 板定义）---
board_build.mcu                 = esp32s3
board_build.flash_mode          = qio
board_build.arduino.memory_type = qio_opi
board_upload.flash_size         = 16MB
board_build.partitions          = default_16MB.csv

; --- 时钟 ---
board_build.f_cpu   = 240000000L
board_build.f_flash = 80000000L

; --- 宏 ---
build_flags =
    -DBOARD_HAS_PSRAM          ; 必须！否则 PSRAM 被内核 undef 掉
    -DARDUINO_USB_MODE=1
    -DARDUINO_USB_CDC_ON_BOOT=0 ; CH343 走 UART0，不用原生 USB CDC

; --- 主机通信 ---
monitor_speed = 115200
upload_speed  = 921600
```

## memory_type 的六个取值

由 `tools\sdk\esp32s3\` 下的预编译库目录决定，命名格式是 `<flash>_<psram>`：

| 取值 | flash | PSRAM | 典型模块 |
|---|---|---|---|
| `qio_qspi` | Quad | Quad SPI | N8R2 |
| `qio_opi` | Quad | **Octal** | **N16R8 / N8R8** |
| `opi_opi` | Octal | Octal | 用 OPI flash 的板子 |
| `opi_qspi` | Octal | Quad | 少见 |
| `dio_qspi` / `dio_opi` | Dual | Quad / Octal | 兼容性优先 |

选错的后果：`opi_*` 系列会让 `_get_board_flash_mode()` 强制改用 `dout` 启动，
并链接到错误的 `sections.ld`，通常直接 bootloop 或 PSRAM 初始化失败。

**怎么判断**：`esptool` 烧录日志出现 `Features: WiFi, BLE, Embedded PSRAM 8MB (AP_3v3)`
说明 PSRAM 在封装内。ESP32-S3 封装内的 8 MB PSRAM 是八线（Octal）的 → `qio_opi`。

## PSRAM 的两个开关（最容易漏）

| 开关 | 作用 | 漏掉的症状 |
|---|---|---|
| `board_build.arduino.memory_type = qio_opi` | 选对预编译 SDK 静态库 | bootloop / PSRAM 初始化失败 |
| `-DBOARD_HAS_PSRAM` | 阻止内核 `#undef CONFIG_SPIRAM` | **能启动、串口正常、PSRAM 恒为 0** |

内核源码 `cores\esp32\esp32-hal-psram.h`：

```c
#ifndef BOARD_HAS_PSRAM
#ifdef CONFIG_SPIRAM_SUPPORT
#undef CONFIG_SPIRAM_SUPPORT
#endif
#ifdef CONFIG_SPIRAM
#undef CONFIG_SPIRAM
#endif
#endif
```

## 分区表

`board_build.partitions` 的值是 `tools\partitions\` 下的文件名。16 MB flash 常用：

| 文件 | app 分区 | 用途 |
|---|---|---|
| `default_16MB.csv` | 2 x 6.25 MB (OTA) | 默认选择 |
| `large_spiffs_16MB.csv` | 小 app + 大 SPIFFS | 要塞文件系统 |
| `app3M_fat9M_16MB.csv` | 2 x 3 MB + 9 MB FAT | 需要 FAT 分区 |
| `huge_app.csv` | 单 app，无 OTA | 不用 OTA 时 |

`default_16MB.csv` 实际内容：

```
# Name,   Type, SubType, Offset,  Size, Flags
nvs,      data, nvs,     0x9000,  0x5000,
otadata,  data, ota,     0xe000,  0x2000,
app0,     app,  ota_0,   0x10000, 0x640000,
app1,     app,  ota_1,   0x650000,0x640000,
spiffs,   data, spiffs,  0xc90000,0x360000,
coredump, data, coredump,0xFF0000,0x10000,
```

编译日志里 `Flash: [ ] 4.3% (used 282965 bytes from 6553600 bytes)` 的
`6553600` = `0x640000` 正是 app0 大小 —— 这行能直接确认分区表生效了。

## 常用 build_flags

```ini
build_flags =
    -DBOARD_HAS_PSRAM          ; PSRAM 必须
    -DCORE_DEBUG_LEVEL=3       ; 0=NONE 1=ERROR 2=WARN 3=INFO 4=DEBUG 5=VERBOSE
    -DARDUINO_USB_CDC_ON_BOOT=0
    -DCONFIG_ARDUINO_LOOP_STACK_SIZE=8192
    -I include                 ; 额外头文件目录
    -D MY_FLAG=42              ; 自己定义的编译期开关
```

`-DCORE_DEBUG_LEVEL` 会和框架自带的定义撞车，出现
`warning: "CORE_DEBUG_LEVEL" redefined`。无害（后出现的生效）；
想彻底干净就加 `build_unflags = -DCORE_DEBUG_LEVEL=0` 先取消框架的定义。

## 多环境与 default_envs

```ini
[platformio]
default_envs = esp32-s3-n16r8        ; 不设的话 pio run 会把每个 env 都编一遍

[env:esp32-s3-n16r8]
board = esp32-s3-devkitc-1
framework = arduino

[env:esp32-s3-n16r8-debug]
extends = env:esp32-s3-n16r8
build_type = debug
build_flags =
    ${env:esp32-s3-n16r8.build_flags}
    -DCORE_DEBUG_LEVEL=5
```

`${env:name.build_flags}` 是 ini 的变量插值语法（不是 shell 展开）。
`build_type = debug` 会换一套编译参数，因此**整个 Arduino 框架要重编**（首次 3–10 分钟）。
只想要详细日志的话，加 `-DCORE_DEBUG_LEVEL=5` 就够了，不必开 `build_type`。

## 其它常用字段

```ini
lib_deps =
    adafruit/Adafruit NeoPixel@^1.12.0
    https://github.com/me/mylib.git
    file://../local_lib

lib_ldf_mode           = chain+   ; 依赖扫描模式，deep+ 太慢时用 chain+
board_build.filesystem = littlefs
extra_scripts          = pre:extra.py
```

## 其它板子模板

```ini
; ESP32-S3 通用（无 PSRAM，或不确定型号时先跑通再说）
[env:esp32-s3]
platform  = espressif32
board     = esp32-s3-devkitc-1
framework = arduino

; ESP32 经典（ESP32-WROOM-32）
[env:esp32dev]
platform  = espressif32
board     = esp32dev
framework = arduino
monitor_speed = 115200
```

## 自查命令

```powershell
# 看某块板到底怎么定义的
Get-Content .\.platformio\platforms\espressif32\boards\esp32-s3-devkitc-1.json

# 列出所有 S3 板
Get-ChildItem .\.platformio\platforms\espressif32\boards\*s3*.json | Select-Object -ExpandProperty Name

# 列出可用分区表
Get-ChildItem .\.platformio\packages\framework-arduinoespressif32\tools\partitions\*.csv

# 确认 memory_type 的合法取值（SDK 库目录名就是取值全集）
Get-ChildItem .\.platformio\packages\framework-arduinoespressif32\tools\sdk\esp32s3 -Directory
```

现成的 R8N16 参考板定义可直接对照：
`.platformio\platforms\espressif32\boards\4d_systems_esp32s3_gen4_r8n16.json` —— 它同时用了
`"memory_type": "qio_opi"`、`"partitions": "default_16MB.csv"` 和
`"-DBOARD_HAS_PSRAM"`，与本项目做法完全一致。

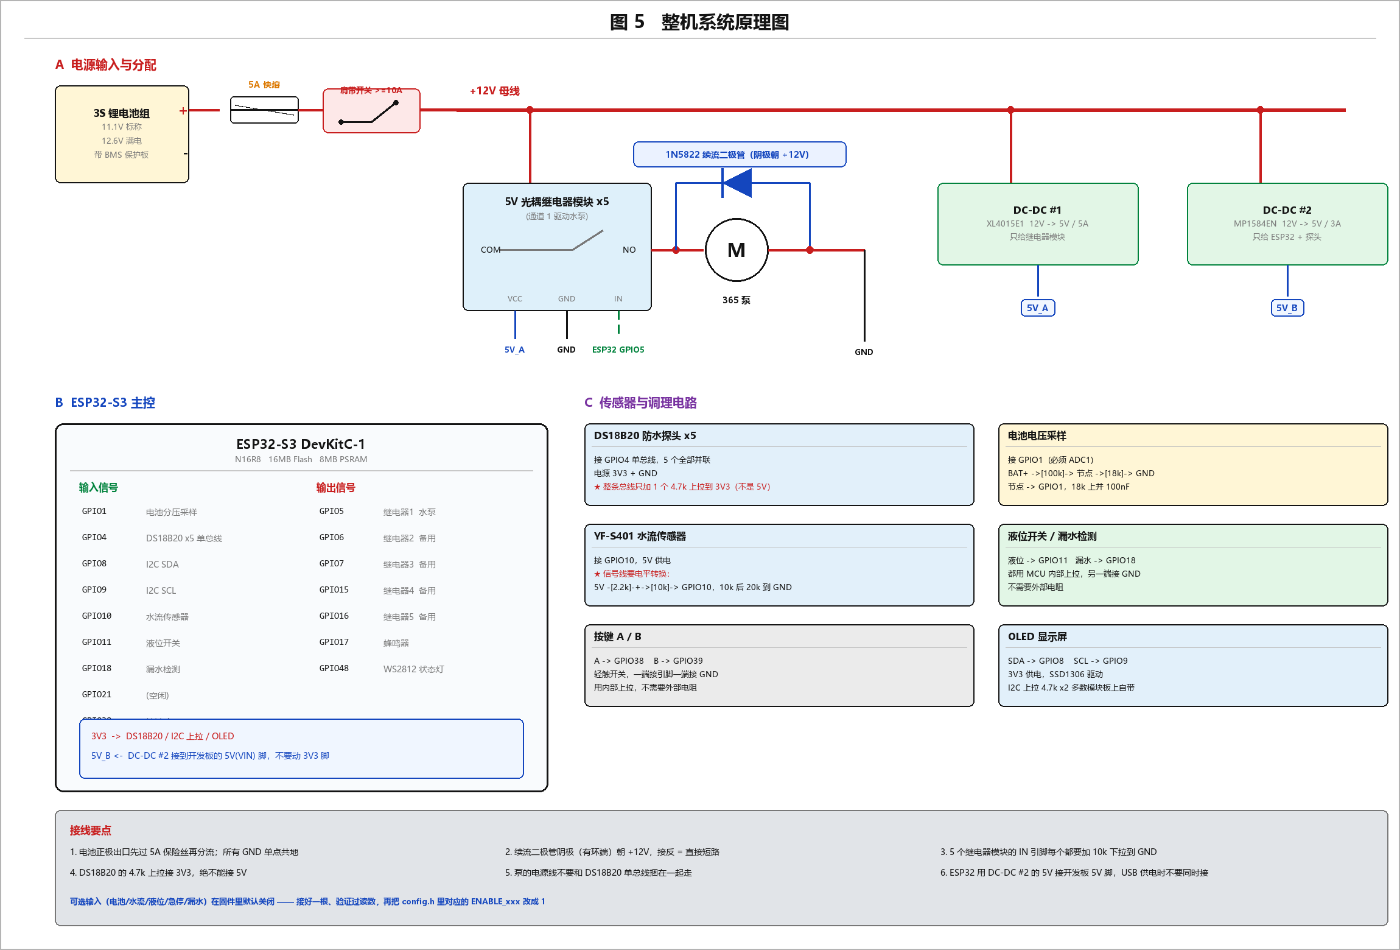
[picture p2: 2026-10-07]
projects/body-cooler/docs/diagrams/fig5_system_schematic.png

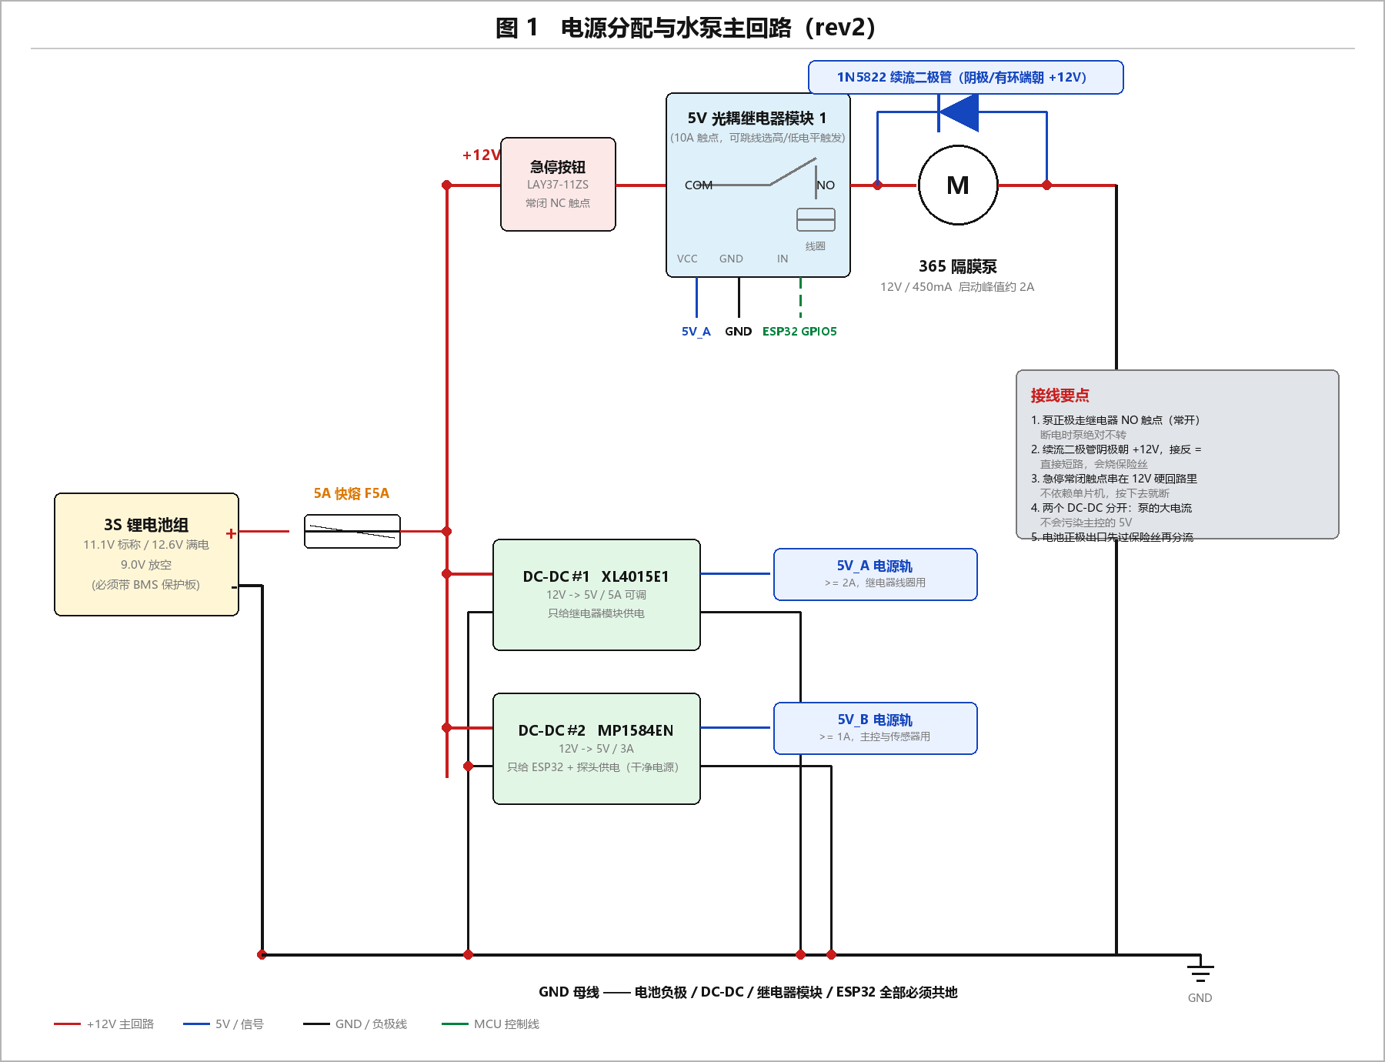
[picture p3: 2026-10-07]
projects/body-cooler/docs/diagrams/fig1_power_pump.png

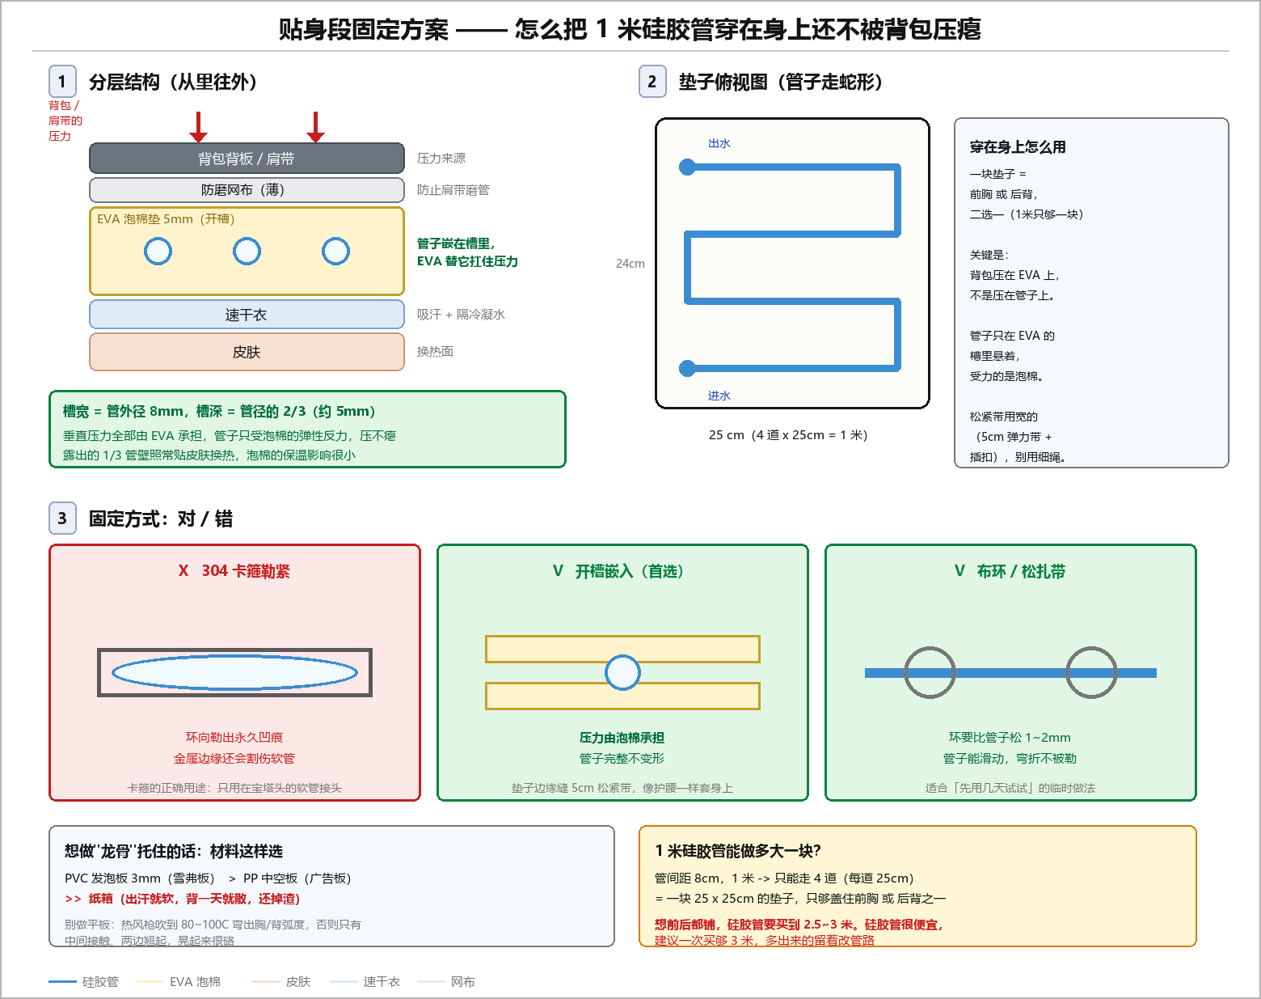
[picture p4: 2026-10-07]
projects/body-cooler/docs/diagrams/fig7_wearable.png

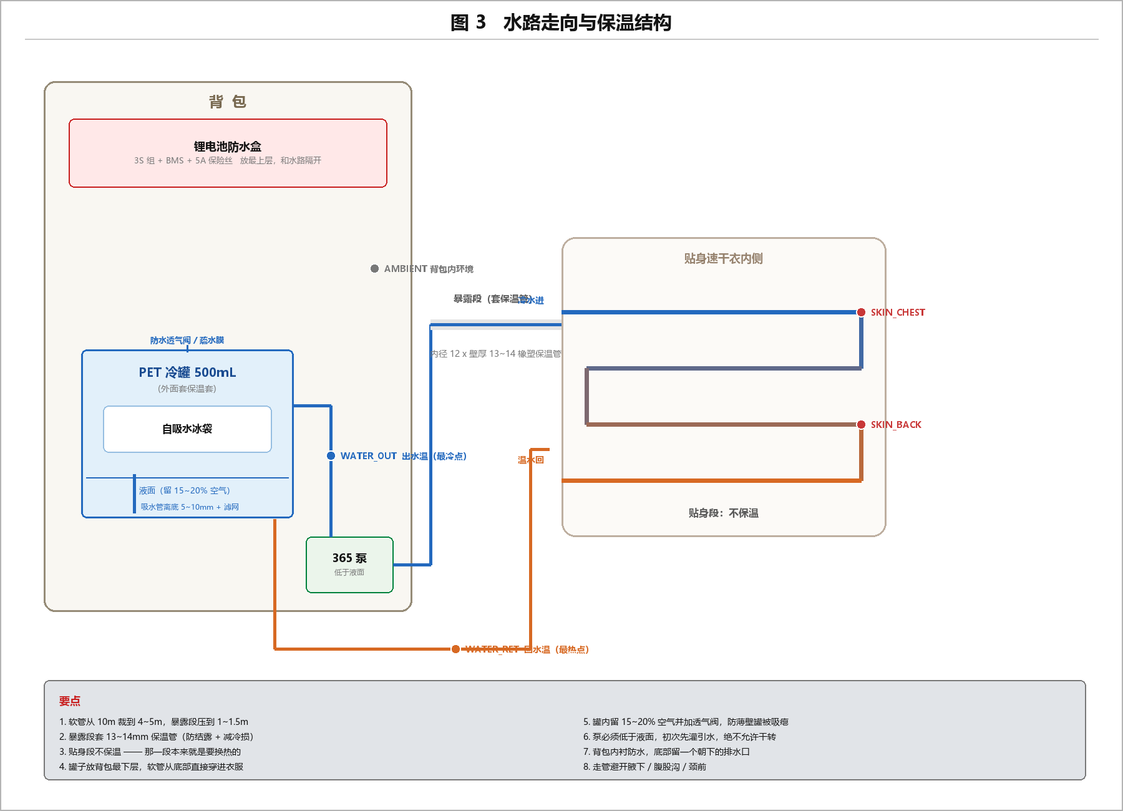
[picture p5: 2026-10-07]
projects/body-cooler/docs/diagrams/fig3_water_loop.png

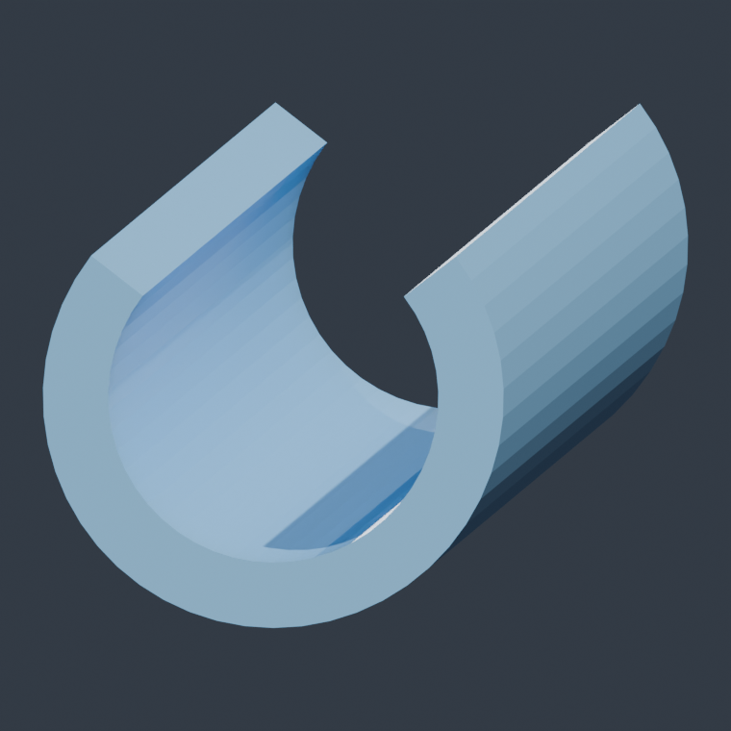
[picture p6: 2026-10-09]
projects/body-cooler/cad/preview_bends_profile.png

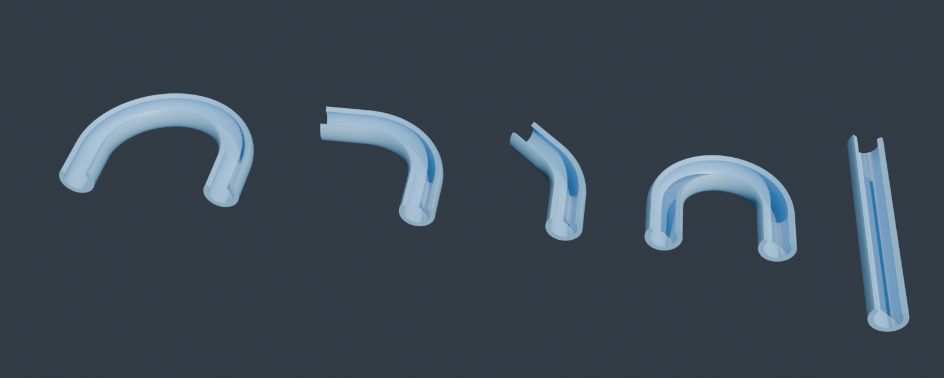
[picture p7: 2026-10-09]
projects/body-cooler/cad/preview_bends.png

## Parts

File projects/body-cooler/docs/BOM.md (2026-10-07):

# 采购清单（具体型号）

> 每一项都给了**能直接复制去搜的型号字符串**和关键参数。价格是 2024-2025 年淘宝散件的常见区间，仅供参考。
> 和 `docs/UPGRADE-PLAN.md` 的阶段编号（P0-x）一一对应。

---

## P0 — 安全与可靠性（必做）

### P0-1 泵续流二极管

| 项目 | 型号 / 规格 | 数量 | 参考价 | 搜索关键词 |
|---|---|---|---|---|
| **首选** | **1N5822** 肖特基二极管，3A / 40V，DO-201AD 直插 | 2 | 1 元/只 | `1N5822 直插 肖特基二极管 DO-201AD` |
| 替代 | **1N5408** 普通整流，3A / 1000V，DO-201AD | 2 | 1 元/只 | `1N5408 直插 整流二极管` |
| 贴片替代 | **SS34**，3A / 40V，SMA 封装 | 5 | 1 元/5只 | `SS34 贴片 肖特基 SMA` |

选 1N5822 的理由：肖特基压降只有 0.4V（普通硅管 0.7V），续流时发热小；
3A 对 0.45A 的泵有 6 倍余量。**DO-201AD 是直插封装，比贴片好焊。**

> 接反 = 直接把 12V 短路，会立刻烧保险丝。装之前用万用表二极管档确认方向。

### P0-2 继电器 IN 引脚的 10k 上拉 / 下拉

| 项目 | 型号 / 规格 | 数量 | 参考价 | 搜索关键词 |
|---|---|---|---|---|
| **电阻** | **10kΩ 1/4W 金属膜电阻 1% 精度**，直插 | 10 | 2 元/50只 | `10K 1/4W 金属膜电阻 1% 50只` |

买 50 只装的一包更划算，剩下的以后到处都用得上。

### P0-3 电源滤波电容

| 项目 | 型号 / 规格 | 数量 | 参考价 | 搜索关键词 |
|---|---|---|---|---|
| 母线储能 | **470µF / 25V 铝电解电容 直插**，φ8×12mm | 3 | 3 元/10只 | `470UF 25V 铝电解电容 直插` |
| 局部储能 | **100µF / 25V 铝电解电容 直插** | 6 | 2 元/10只 | `100UF 25V 铝电解电容 直插` |
| 高频去耦 | **0.1µF / 50V 瓷片电容（标号 104）** | 10 | 1 元/20只 | `104 瓷片电容 0.1uF 50V` |

电解电容品牌优先级：红宝石 Rubycon YXA > 尼吉康 Nichicon > 国产法拉 Fara。
这个位置**别买杂牌**：泵启停的纹波电流很大，劣质电解几个月就鼓包。

### P0-4 保险丝 + 电池保护板

| 项目 | 型号 / 规格 | 数量 | 参考价 | 搜索关键词 |
|---|---|---|---|---|
| **保险丝座（推荐）** | **小号插片式保险丝座**（APS / 迷你款），带线 | 2 | 4 元 | `小号插片保险丝座 带线` |
| **保险丝** | **5A 迷你插片保险丝（F5A 快熔）** | 5 | 3 元/5只 | `小号插片保险丝 5A 快熔` |
| 替代（玻璃管） | 5×20mm 保险丝座带线 + 5×20mm F5A 玻璃管 | 1 套 | 3 元 | `5*20 保险丝座 带线 F5A` |
| **电池保护板** | **3S 12V 40A 同口 带均衡 锂电池保护板** | 1 | 12 元 | `3S 12V 40A 同口 锂电池保护板 带均衡` |

要点：

* 插片式比玻璃管式好：接触电阻小、抗震、插拔方便。车用场景本来就是为振动设计的。
* **F5A 快熔**（不是 T5A 慢熔）。额定 5A 对 2A 的启动冲击有 2.5 倍余量，不会误熔；
  对短路电流又能及时切断。
* BMS 选 **40A 同口带均衡**。你的实际负载只有 0.7A / 峰值 2A，10A 版也够用，
  但 40A 版的内阻更低、压降更小，且给以后留余量。**「同口」= 充放电共用一个口**，
  比分口少一组线，接线简单得多。

### P0-5 总电源开关（**不是** 22mm 蘑菇头急停）

> **修正**：22mm 蘑菇头急停按钮是给机柜 / 设备面板设计的，戴在身上的背包用不上它。
> 需要的不是「大按钮」，而是**一个不解背包就够得着的开关**。

| 项目 | 型号 / 规格 | 数量 | 参考价 | 搜索关键词 |
|---|---|---|---|---|
| **首选** | **肩带用自锁翘板开关**，船型开关 KCD1-101，2 脚 2 档，**≥10A** | 1 | 5 元 | `KCD1-101 船型开关 2脚2档 10A` |
| 替代 | **防水自锁按钮开关**（12mm/16mm 金属，自锁式，2 脚） | 1 | 10 元 | `12mm 自锁按钮开关 防水 2脚` |
| 安装 | 开关固定在**肩带**上，手指不离开行进动作就能摸到 | — | — | |

为什么选 **11ZS**（1 常闭 1 常开）：

* **常闭那组给软件**（GPIO21）：不按时闭合到 GND，按下或线断就被内部上拉拉高 —— **失效安全**
* **常开那组串在泵的 12V 硬回路里**：按下时断开泵电源，不依赖单片机
* 「旋转复位」比「拉出复位」好：背包里不容易被蹭开

### P0-6 漏水检测线

| 项目 | 型号 / 规格 | 数量 | 参考价 | 搜索关键词 |
|---|---|---|---|---|
| **自制（推荐）** | **1.5mm² 单芯裸铜线**，剥皮取铜芯，两根平行铺开间距 2~3mm | 1 | 0 元 | 手边就有 |
| 买成品 | **2.54mm 镀金双排排针**，掰成两针一条 | 5 条 | 2 元 | `2.54mm 镀金排针 双排` |
| 接线 | 细硅胶线（耐弯折） | 1m | 3 元 | `24AWG 硅胶线 多股软线` |

**不要镀锡**：锡在潮湿环境会钝化，几个月后就不导电了。用裸铜或镀金。

### P0-7 保温

| 项目 | 型号 / 规格 | 数量 | 参考价 | 搜索关键词 |
|---|---|---|---|---|
| **软管保温** | **橡塑保温管，内径 12mm × 壁厚 13mm**，黑色闭孔发泡 | **2 m** | 10 元 | `橡塑保温管 内径12mm 壁厚13mm 空调保温管` |
| 弯头/接头处 | **自粘发泡保温带**（保温管套不进弯头的位置补缠） | 1 卷 | 8 元 | `自粘保温带 发泡 橡塑` |
| **罐体保温** | **3mm 氯丁橡胶潜水料片材**（或加厚铝箔保温袋） | 1 张 | 10 元 | `潜水料 片材 3mm 氯丁橡胶` |
| 绑扎 | **20mm 宽魔术贴绑带**（背胶或穿扣） | 2 m | 8 元 | `魔术贴绑带 20mm 背胶` |

> **尺寸别买错**：8×11 软管的意思是**内径 8mm、外径 11mm**。
> 所以保温管的内径必须 **>= 12mm** 才套得进去。买内径 9mm 的会完全套不上。
> （如果贴身段换成 6×8 硅胶管，那一段的外径是 8mm，用内径 9mm 的保温管。）
>
> **壁厚选 13mm 不要选 9mm**：9mm 保温后外表面只有 25.0 C，
> 而 30 C / 80%RH 的露点是 26.2 C —— 还是会结露。13mm 能压到 26.6 C。
>
> **只需要买 1.5~2m，不要买 5m。** 贴身那一段软管**不用保温**（它贴着皮肤，
> 本来就是要换热的）。把罐子和泵放在背包最下层，软管从背包底部直接穿进衣服，
> 暴露段可以压到 1~1.5m。买多了又贵又臃肿。

---

## P1 — 传感器与显示

### P1-1 电池电压采样

| 项目 | 型号 / 规格 | 数量 | 参考价 | 搜索关键词 |
|---|---|---|---|---|
| 分压上臂 R1 | **100kΩ 1/4W 金属膜电阻 1%** | 4 | 1 元 | `100K 1/4W 金属膜电阻 1%` |
| 分压下臂 R2 | **18kΩ 1/4W 金属膜电阻 1%** | 4 | 1 元 | `18K 1/4W 金属膜电阻 1%` |
| 采样滤波 | **100nF / 50V 瓷片电容（104）** | 4 | 共用 P0-3 | 同 P0-3 |

为什么用 1% 精度：分压比直接决定电压读数准不准。5% 的碳膜电阻会让读数偏 2~3%，
而 1% 金属膜只差 0.2%，比 ADC 本身的误差还小，可以忽略。

### P1-2 水流传感器

| 项目 | 型号 / 规格 | 数量 | 参考价 | 搜索关键词 |
|---|---|---|---|---|
| **首选** | **YF-S401**，量程 0.3~6 L/min，标称 5880 脉冲/升，4.5~18V 供电，霍尔式 | 1 | 25 元 | `YF-S401 水流传感器 8mm 宝塔` |
| 接口转接（备用） | **8mm 转 6mm 宝塔变径接头**（如果买到的是 6mm 口版本） | 2 | 8 元 | `宝塔变径接头 8转6` |
| 分压 R1 | **10kΩ 1/4W 金属膜 1%** | 2 | 共用 P0-2 | 同 P0-2 |
| 分压 R2 | **20kΩ 1/4W 金属膜 1%** | 2 | 1 元 | `20K 1/4W 金属膜电阻 1%` |
| **上拉（不能省）** | **2.2kΩ 1/4W 金属膜 1%** | 2 | 1 元 | `2.2K 1/4W 金属膜电阻 1%` |
| 替代（流量更低） | **YF-S402**，量程 0.1~3 L/min | 1 | 28 元 | `YF-S402 水流传感器` |
| 不推荐 | YF-S201（量程 1~30 L/min）—— 你的实际流量可能只有 0.8~1.3 L/min，卡在量程下边缘 | | 15 元 | |

选型依据：365 泵自由流量约 1.5 L/min，接上 4~5m 的 8mm 管之后实际大概 0.8~1.3 L/min。
**YF-S401 的 0.3~6 L/min 正好覆盖**；YF-S201 的 1 L/min 下限太危险，流量偏低时会直接读 0。

> **接口形式一定要在下单前问客服确认。** YF-S401 是净水器 / 咖啡机行业大量使用的通用件，
> 市面上至少有三种接口：**6mm 宝塔快接口**（最常见）、**8mm 宝塔快接口**、**1/2 外螺纹**。
> 你的软管内径是 8mm，所以要选 **8mm 宝塔口**版本；买到 6mm 口的就得配一个 8 转 6 变径。
>
> **脉冲数也以卖家的实际标注为准。** 5880 脉冲/升（对应的频率公式是 F(Hz) = 98 x Q(L/min)）
> 是这个型号最常见的标称值，但不同批次、不同芯片会有出入。
> **好在固件里本来就有标定命令**：接好后跑 `flow` 看读数，用量杯接 1 升水，
> 按比例改 `flowcal <脉冲/升>`，然后 `savecfg` 持久化。实测标定永远比抄参数准。

### P1-3 液位开关

| 项目 | 型号 / 规格 | 数量 | 参考价 | 搜索关键词 |
|---|---|---|---|---|
| **首选** | **M10 螺纹 304 不锈钢浮球开关，常开型（NO）**，线长 30cm | 1 | 6 元 | `M10 不锈钢浮球开关 常开 水位传感器` |
| 替代（耐腐蚀） | **PP 塑料浮球开关 M8**（适合纯净水，不会有金属离子析出） | 1 | 5 元 | `PP 浮球开关 M8 常开` |
| 密封 | **M10 硅胶密封垫圈**（配罐盖开孔） | 5 | 2 元 | `M10 硅胶垫圈 密封圈` |

选 **常开（NO）**：水位上升 → 浮子抬起 → 触点闭合 → 引脚被拉到 GND → 固件判定「有水」。
大多数 M8/M10 型的浮子环可以翻转来切换常开/常闭，但直接买对的更省事。

### P1-4 OLED 显示屏

| 项目 | 型号 / 规格 | 数量 | 参考价 | 搜索关键词 |
|---|---|---|---|---|
| **屏幕** | **0.96 寸 OLED，SSD1306 驱动，128×64 分辨率，I2C 4 针**，白字 或 蓝字 | 1 | 15 元 | `0.96寸 OLED SSD1306 I2C 12864 4针` |
| 转接线 | **XH2.54 4P 转杜邦线** 20cm | 2 | 3 元 | `XH2.54 4P 转杜邦线` |
| 驱动库 | PlatformIO: `olikraus/U8g2`（最省内存）或 `adafruit/Adafruit SSD1306` | — | 0 元 | — |

> **必须买 SSD1306，不要 SH1106。** 两者引脚完全兼容、外观一样，但驱动方式不同。
> 买成 SH1106 而程序按 SSD1306 驱动 → 花屏或者图像偏移 2 个像素。
> 分辨方法：商品标题写了 SSD1306 就是；不确定就问客服要驱动 IC 型号。

I2C 地址常见是 **0x3C**（少数是 0x3D），固件里可以直接扫描确认。

### P1-5 贴身段软管

| 项目 | 型号 / 规格 | 数量 | 参考价 | 搜索关键词 |
|---|---|---|---|---|
| **硅胶管** | **6×8mm 食品级硅胶软管**（内径 6 / 外径 8），耐温 -40~200°C | 5 m | 20 元 | `6*8 硅胶管 食品级 内径6mm` |
| **变径接头** | **8mm 转 6mm 宝塔变径接头**，304 不锈钢 或 尼龙 | 2 | 10 元 | `宝塔变径接头 8转6 不锈钢` |
| 卡箍 | **304 不锈钢卡箍，夹持范围 8~12mm** | 10 | 5 元 | `304不锈钢卡箍 8-12mm` |

为什么要换：8×11 的 PVC 管**偏硬**，盘在背上长时间压着会形成压痕和压迫点。
6×8 硅胶管更软、更细、更贴合，而且硅胶导热比 PVC 好一点，冷量传递更直接。

---

## P2 — 结构与热工

| 项目 | 型号 / 规格 | 数量 | 参考价 | 搜索关键词 |
|---|---|---|---|---|
| 减震垫 | **5mm 高密度 EVA 泡棉板**（或 10mm 海绵） | 1 张 | 5 元 | `EVA泡棉板 5mm 高密度 减震` |
| 电池防水盒 | **IP67 ABS 防水接线盒 200×120×75mm**，带密封圈 | 1 | 20 元 | `IP67 防水盒 200*120*75 ABS` |
| 控制盒 | **IP65 防水盒 150×100×70mm** | 1 | 15 元 | `IP65 防水盒 150*100*70` |
| 隔板 | **3mm PVC 硬板**（自制背包内隔板） | 1 张 | 10 元 | `PVC硬板 3mm 白色` |
| 排水口 | **疏水透气阀 / 防水透气膜**（罐盖透气口用） | 5 | 8 元 | `防水透气阀 疏水 透气膜` |

---

## 电源模块（替换掉含糊的「DC-DC 稳压模块」）

你原来写的是「DC-DC 稳压模块 12V→(3.3V/5V/2.5V/12V) ×3」，这个描述太含糊，换具体型号：

| 用途 | 型号 / 规格 | 数量 | 参考价 | 搜索关键词 |
|---|---|---|---|---|
| **泵 + 继电器 5V 轨** | **XL4015E1** 5A 可调降压模块（带散热片） | 1 | 6 元 | `XL4015 5A 可调降压模块` |
| **ESP32 5V 轨** | **MP1584EN** 3A 迷你降压模块（效率 90%+，静态电流小） | 1 | 4 元 | `MP1584EN 降压模块 3A 可调` |
| 可选（带数显） | XL4015 带电压电流数显版 | 1 | 12 元 | `XL4015 数显降压模块` |
| **不推荐** | LM2596S —— 效率只有约 75%，静态电流约 10mA，电池长期供电不划算 | | 3 元 | |

要点：

* **XL4015E1**：5A 输出，效率 90%，带恒流恒压模式，适合带感性负载。
* **MP1584EN**：3A，体积小，效率 90%+，适合给主控供电。EN 使能脚可以留作以后做低功耗。
* 你提到的 **2.5V 档应该是笔误**（可能是 2.5A），这个项目用不到 2.5V。
* ESP32 开发板自己的 3V3 由板上 LDO 产生，**从 DC-DC 输出 5V 接到开发板的 5V/VIN 脚**即可，
  不要用 12V→3.3V 直供 3V3 脚（那样会绕过板上 LDO，且 USB 一插就打架）。

---

## 选配：把机械继电器换成 MOSFET 开关

| 项目 | 型号 / 规格 | 数量 | 参考价 | 搜索关键词 |
|---|---|---|---|---|
| **首选** | **XY-MOS 15A 直流 MOSFET 开关模块**，高电平触发，带散热片 | 1 | 12 元 | `XY-MOS 15A MOS管开关模块 直流` |
| 替代 | **IRF3205 MOSFET 开关模块 15A** | 1 | 8 元 | `IRF3205 MOS管开关模块` |

换掉机械继电器的好处：

| | 机械继电器 | MOSFET 模块 |
|---|---|---|
| 机械寿命 | 约 10 万次 | 无限制 |
| 触点电弧 | 有（感性负载更严重） | 无 |
| 开关噪声 | 咔哒声 | 完全静音 |
| 开关速度 | 10ms 级 | 微秒级 |
| 发热 | 无 | 有一点（几瓦），要贴散热片 |

**但最短启停时间仍然要保留** —— 那是为了保护泵本身的阀片和膜片，跟继电器无关。
续流二极管也仍然需要（感性负载的规矩不变）。

---

## 电阻：买什么包最划算

这个项目一共用到 **6 种阻值、约 15 只**：

| 阻值 | 用在哪 | 数量 |
|---|---|---|
| **10kΩ** | 继电器 IN 上拉/下拉 x5、水流分压 R1 x1 | 6 |
| **4.7kΩ** | DS18B20 单总线上拉 x1、I2C SDA/SCL 上拉 x2 | 3 |
| **2.2kΩ** | 水流传感器上拉（不能省） | 1 |
| **20kΩ** | 水流分压 R2 | 1 |
| **100kΩ** | 电池分压 R1 | 1 |
| **18kΩ** | 电池分压 R2 | 1 |

### 如果只买一包 10k（100 只）——不行

| 位置 | 原值 | 能不能用 10k 顶 | 说明 |
|---|---|---|---|
| 继电器 IN 上拉/下拉 | 10k | **可以** | 本来就是 10k |
| 水流分压 R1/R2 | 10k / 20k | **可以** | R1 正好是 10k |
| 按键 / 开关上拉 | — | 不用 | 用 MCU 内部上拉 |
| I2C SDA/SCL 上拉 | 4.7k x2 | 勉强 | 10k 也能跑，但总线电容大时波形变钝 |
| DS18B20 单总线上拉 | 4.7k | **单只不行** | 10k 上升沿太慢，5 个探头 + 长线会偶发读失败。**用两只 10k 并联 = 5k** 就可以 |
| 水流传感器上拉 | 2.2k | **不行** | 10k 太弱，高电平会被分压电阻拽到门限以下 |
| 电池分压 R1 / R2 | 100k / 18k | **绝对不行** | 见下方计算，会烧引脚 |

**为什么电池分压绝对不能用 10k/10k：**

```
12.6V 经 10k / 10k 分压  ->  引脚上 6.30V
ESP32-S3 引脚绝对最大电压 = VDD + 0.3 = 3.6V
6.30V >> 3.6V  ->  触发内部保护二极管大电流，烧引脚甚至烧片子
```

理论上你可以用 **10 只 10k 串联 = 100k** 当 R1、**2 只 10k 串联 = 20k** 当 R2，
然后把 `include/config.h` 里的 `BATT_DIV_R2_KOHM` 改成 `20.0f` —— 能跑，
但一个分压用掉 12 只电阻实在没必要，不如买包。

### 推荐买法

| 方案 | 型号 / 规格 | 参考价 | 搜索关键词 |
|---|---|---|---|
| **最推荐** | **1/4W 金属膜 1%，130 种值 x 20 只 = 2600 只，盒装，1ohm ~ 3Mohm** | 30 元 | `1/4W 金属膜电阻包 130种 每种20只 盒装 1%` |
| 够用 | 1/4W 金属膜电阻包，1% 精度，30 种值 x 20 只 = 600 只 | 12 元 | `1/4W 金属膜电阻包 1% 30种 600只` |
| 省钱 | 只买 10k 一包（100 只）+ 4.7k / 2.2k / 20k / 100k / 18k 各买一小包 | 约 8 元 | `10K 1/4W 金属膜电阻 100只` |

**130 种盒装完全够用，而且是最省事的选择。** 理由：

1. 这个项目要的 6 个阻值 **全都是 E24 标准值**，任何覆盖 1ohm ~ 1Mohm 的包都必然包含：
   `2.2k` `4.7k` `10k` `18k` `20k` `100k`
2. **功率绰绰有余**。全项目单只电阻的最大功耗出现在水流传感器的 2.2k 上拉上：

   | 位置 | 实际功耗 |
   |---|---|
   | 2.2k 水流上拉（传感器拉低时） | 11.4 mW |
   | 10k 继电器 IN 下拉 | 2.5 mW |
   | 4.7k 单总线 / I2C 上拉 | 2.3 mW |
   | 100k + 18k 电池分压（整条支路） | 1.4 mW |
   | 10k + 20k 水流分压（整条支路） | 0.8 mW |

   最大 11.4 mW，1/4W（250 mW）有 **22 倍余量**；就算买到的是 1/8W 也有 11 倍，照样够。
3. 以后做别的项目也不用再买电阻了。

**下单前只核对一件事**：商品标题必须写 **「1% 金属膜」**。
市面上还有「1/4W 碳膜 5%」的同类盒装，长得几乎一样但精度差 5 倍。
碳膜也不是不能用（分压电阻实测后把实际阻值填进 `config.h` 的 `BATT_DIV_R1_KOHM` / `R2` 即可补偿），
但既然价格差不多，直接买 1% 金属膜省掉这一步。

唯一的小缺点：2600 只的盒子大概 20 x 15 x 4 cm，占地方，而且这辈子用不完。
但电阻是通用耗材，不会坏也不会过期。

买电阻包时认准三个参数：**1/4W 功率**、**1% 精度**、**金属膜**（不是碳膜）。
30 种值的包一定包含 10 / 22 / 47 / 100 / 220 / 470 / 1k / 2.2k / 4.7k / 10k / 20k / 100k 这些常用值。

> 电阻不贵也不坏，买多了囤着无所谓。100 只 10k 一包才 2 块钱，
> 但要**再单独补 4.7k / 2.2k / 20k / 100k / 18k 这 5 种**，凑单运费可能比电阻本身贵。
> 直接上 600 只的混装包最省事。

---

## 密封件：硅胶圈 / 尼龙垫 / 红钢纸垫，别买混了

**它们不是同类件，不能互相替代：**

| 件 | 材质 | 作用 | 原理 |
|---|---|---|---|
| **硅胶 O 型圈 / 平垫** | 弹性体 | **密封** | 靠压缩变形填满微观缝隙 |
| **尼龙平垫** | 刚性 | **承力** | 几乎不压缩，把螺母压力分散到更大面积 |
| **红钢纸垫** | 半刚性纤维 | 密封 + 承力 | 遇水微膨胀，水管行业标准件 |

**尼龙是硬的，压不出形变，拿来当密封件用会漏。**

正确叠法（从罐内到罐外）：

```
宝塔头法兰 --> 硅胶圈 --> PET 罐壁 --> 尼龙平垫 --> 螺母
             (密封)                   (承力, 保护薄壁)
```

PET 罐壁只有 1~1.5mm 厚，**建议加尼龙平垫**，否则螺母的压紧力集中在一圈薄壁上，
拧紧时容易把罐壁压凹甚至压裂。

**尺寸怎么定**（务必实测，别照抄）：

| 件 | 尺寸规则 |
|---|---|
| O 型圈 | 内径 = 螺纹实测外径 - 1mm（要能箍住），线径 2mm |
| 平垫 | 内径 = 螺纹实测外径 + 0.5mm，外径 <= 法兰压紧面直径 |
| 尼龙平垫 | 内径同平垫，外径可以比法兰略大（它只承力） |

> **英制管件的『分』不是螺纹直径。** 4 分 = 1/2 英寸指的是**管子内径的俗称**，
> 实际螺纹外径是 **20.955mm**；6 分（3/4"）是 **26.441mm**。
> 所以花洒 / 热水器用的 4 分垫圈外径在 20~26mm 量级，
> 而 M12 穿板接头的法兰压紧面只有 16~18mm 左右 —— **尺寸对不上，压不实还会跑位。**

## 端子排（推荐用接线端子搭，不用画板也不用焊）

| 项目 | 型号 / 规格 | 数量 | 参考价 | 搜索关键词 |
|---|---|---|---|---|
| **电源端子排 X1** | **TB-1508** 固定式接线端子排，8 位，10A | 1 | 3 元 | `TB-1508 接线端子排 8位 10A` |
| **引脚端子排 X2** | **TB-1510** 固定式接线端子排，10 位 | 2 | 4 元 | `TB-1510 接线端子排 10位` |
| 替代（可拼接） | **CH-2** 可拼接接线端子排，10A | 按需 | 5 元 | `CH-2 接线端子排 可拼接 10A` |
| 跳线 | 短的多股软线，把同电位的端子并联起来 | 若干 | — | 手边线头就行 |

**端子排的好处**：模块的线拧在端子上，改线不用动 ESP32，也不用焊。
代价是多一层接触点，所以要**拧紧**，并且定期复紧。

接线顺序：**先接 GND → 再接电源 → 最后接信号**，这样即使接错也不会烧东西。
上电前用万用表通断档确认 **+12V 和 GND 之间不能短路**。

对应图纸：`docs/diagrams/fig6_terminal_wiring.png`

## 通用辅料

| 项目 | 型号 / 规格 | 数量 | 参考价 | 搜索关键词 |
|---|---|---|---|---|
| 快速接线端子 | **WAGO 221 系列**（2 孔 / 3 孔 / 5 孔混装） | 1 盒 | 15 元 | `WAGO 221 快速接线端子 混装` |
| 热缩管 | **2:1 热缩管套装，φ2~10mm 混装**（黑红双色） | 1 盒 | 10 元 | `热缩管套装 2:1 混装 2-10mm` |
| 防水硅胶 | **卡夫特 K-704 硅橡胶**（白色或透明，室温固化） | 1 支 | 8 元 | `卡夫特 K-704 硅橡胶 防水` |
| 尼龙扎带 | 3×100mm 与 4×150mm 混装 | 1 包 | 8 元 | `尼龙扎带 3*100 混装` |
| 多股软线 | **22AWG 与 18AWG 硅胶多股软线**（红黑各一） | 各 5m | 15 元 | `硅胶线 18AWG 22AWG 多股软线` |
| 万用表（没有的话） | **优利德 UT136B+** 或 **胜利 VC890C+** | 1 | 60 元 | `优利德 UT136B+ 万用表` |

---

## 避坑清单（容易买错的东西）

| # | 坑 | 正确做法 |
|---|---|---|
| 1 | OLED 买成 SH1106 | 认准标题写 **SSD1306**；不确定就问客服驱动 IC 型号 |
| 2 | 保温管套不进软管 | 8×11 管的外径是 **11mm**，保温管内径必须 **>= 12mm** |
| 3 | 水流传感器卡在量程外 | 选 **YF-S401**（0.3~6 L/min），别选 YF-S201（1~30 L/min） |
| 4 | 水流传感器接口不匹配 | YF-S401 有 6mm / 8mm 宝塔口 和 1/2 外螺纹三种版本，**下单前问客服**，要 8mm 的 |
| 5 | 浮球开关常开常闭买反 | 选**常开 NO**（水位上升闭合）；多数型号可翻转浮子环改，但直接买对最好 |
| 6 | 保险丝选成慢熔 | 要 **F5A 快熔**，不要 T5A 慢熔 |
| 7 | BMS 买成分口 | 选**同口**，少一组线，接线简单 |
| 8 | 二极管方向接反 | 阴极（有环的一端）接 +12V。装前用万用表二极管档确认 |
| 9 | 电阻买成 5% 碳膜 | 分压电阻要 **1% 金属膜**，否则电压读数偏 2~3% |
| 10 | MOSFET 模块买成高边 | 低边（接负载负极）最常见最便宜；高边要带电荷泵的型号，贵且难找 |
| 11 | 电解电容买杂牌 | 泵启停纹波大，劣质电解几个月就鼓包。选红宝石 / 尼吉康 |
| 12 | DC-DC 买 LM2596 | 效率 75% + 静态 10mA，电池供电不划算。选 XL4015 / MP1584EN |
| 13 | 只买一种阻值的电阻 | 电池分压的 100k/18k 不能用 10k 顶（会烧引脚），直接买混装电阻包 |
| 14 | 水流传感器上拉只用内部 | 必须自加 2.2k 上拉到 5V，否则高电平只有 2.14V，低于 2.475V 门限识别不到 |

---

## 最小可执行采购单（今晚就想动手）

如果只想先解决**安全问题**，买这 5 样就够，一共不到 30 块：

| 型号 | 数量 | 价格 |
|---|---|---|
| 1N5822 肖特基二极管 DO-201AD | 2 只 | 2 元 |
| 10kΩ 1/4W 金属膜电阻（50 只装） | 1 包 | 2 元 |
| 小号插片保险丝座 + 5A 保险丝 | 1 套 | 7 元 |
| 470µF/25V 电解 + 104 瓷片（各 10 只装） | 各 1 包 | 5 元 |
| 橡塑保温管 内径12mm × 壁厚9mm | 2 m | 10 元 |
| **合计** | | **约 26 元** |

这五样对应 P0-1 / P0-2 / P0-4 / P0-3 / P0-7，
能把「继电器几个月就烧黑」和「ESP32 随机复位」这两个最要命的问题解决掉。

---

## 需要额外确认的接口尺寸

下单前用卡尺量一下这三个尺寸，能省掉一次退换货：

| 要量的东西 | 为什么 |
|---|---|
| 现有 8×11 软管的**实际外径** | 决定保温管内径（标称 11mm，实测可能 10.5~11.5） |
| 穿板宝塔头的**螺纹实际外径** | 标称 M12，不同厂家实测 11.8~12.2，决定开孔钻头尺寸 |
| PET 罐盖的**壁厚** | 决定液位开关和透气阀的螺纹长度够不够 |

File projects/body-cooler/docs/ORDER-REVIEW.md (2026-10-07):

# 京东订单核对（对照 docs/BOM.md）

> 20 笔订单，合计约 **1124.72 元**（剔除存疑的 R07 后约 797.72 元）。
> 下面按「买对了 / 要确认 / 买错了 / 还没买」四类过一遍。

---

## 一、买对了（可以直接用）

| 订单 | 商品 | 判定 | 备注 |
|---|---|---|---|
| R02 | 阿乐斯橡塑保温管 **12mm × 厚14mm**，2m × 3 | 正确 | 内径 12mm 正好套 8×11 管（外径 11mm）。**壁厚 14mm 比我建议的 13mm 还好**，外表面温度更高、更不容易结露。只是买了 6m，实际只需 1.5~2m |
| R03 | 直插铝电解 **25V 470µF 8×12**，20 个 × 3 | 正确 | 正是推荐的规格 |
| R04 | 瓷片电容 **104 / 0.1µF / 50V**，100 个 × 3 | 正确 | |
| R05 | 二极管元件包 8 种 100 只（**含 1N5822 和 1N5408**） | 正确 | 续流二极管有了 |
| R06 | **1/4W 金属膜 1%，130 种 × 20 只**，2 盒 | 正确 | 正是推荐的型号，而且买了两盒 |
| R13 | 304 不锈钢卡箍 **Φ6-12mm**，10 个 × 4 | 正确 | 夹 11mm 外径软管正好 |
| R15 | 穿板宝塔直通 **外径 8mm / 螺纹 M12** × 5 | 正确 | |
| R16 | 食品级 PET 密封罐 **100×150mm**，5 个装 × 3 | 正确 | 拿到 15 个，比原计划多 |
| R18 | 丢石头 **5V 光耦继电器模块 1 路 10A 触发电平可调** × 5 | 正确 | 和固件 `RELAY_ACTIVE_HIGH` 的假设一致 |
| R19 | 透明软管 **内径 8 / 外径 11mm**，10m | 正确 | |
| R09 | 12.6V 2A 电源适配器 | 正确 | 配 3S 电池 |
| R07 | 杜邦线混装 | 可用 | ⚠️ 数量 3、实付 **327 元**，纯杜邦线不可能这个价，建议核对订单里是不是还夹了别的东西 |

---

## 二、买错了（必须处理）

### ❌ R21：DS18B20 买成了「模块」，不是「防水探头」

订单原文：`DS18B20温度传感器 测温模块 开发板DS18B20 TO-92 温度采集器`

这是**带 PCB 小板的模块版**（板上焊一个 TO-92 直插 + 4.7k 上拉 + 3 针排针），不是不锈钢封装的防水探头。

三个问题：

1. **不能泡水** —— 测罐内水温必须用防水探头，模块泡水就废了
2. **不能贴皮肤** —— 硬质 PCB 压在身上是压疮源，而且没有引线
3. **只有 3 个**，项目需要 5 个

还有一个电气问题：**模块自带上拉电阻**。5 个模块挂在同一条 1-Wire 总线上，
就是 5 个 4.7k 并联 = **940Ω**，远低于规范值（4.7k）。
1-Wire 总线**整条只允许一个上拉**。

**要补买**：`DS18B20 防水探头 不锈钢 1米线` × 5（约 25 元）

买回来的模块也别扔，可以当**室温参考**或者接在面包板上做调试用 ——
但记住**只保留一个模块的上拉电阻**，其余四个把板上的 4.7k 拆掉或者干脆只用一个。

### ❌ R08 + R20：水泵买成了「小潜水泵」，不是 365 隔膜泵

订单原文：`登仕唐 DC 小潜水泵自吸泵 迷你喷泉 3V/4.5V/5V/6V/12V 直流电机马达 卧式（裸线）`

这是**鱼缸 / 喷泉 / 假山用的微型潜水泵**（离心式），和 365 隔膜泵完全是两种东西：

| | 小潜水泵 | 365 隔膜泵 |
|---|---|---|
| 安装 | **必须完全浸在水里** | 可外置，自吸 |
| 扬程 | 通常 0.3~1.5 m | 20~50 m |
| 流量 | 随扬程急剧下降 | 容积式，扬程影响小 |
| 对管路阻力 | 很敏感 | 不敏感 |
| 电机发热 | **直接进到水里**（给冷却液加热） | 排到空气里 |

**关键风险是扬程**。你这套管路要克服：

```
4~5m 的 8mm 管沿程阻力   约 0.15 m 水柱
背包到胸口的垂直提升     约 0.5 m 水柱
宝塔接头 + 弯头局部损失    约 0.3 m 水柱
                          ------------
                          合计约 1.0 m 水柱
```

而这类小潜水泵的**最大扬程往往只有 0.5~1.5m**，工作在 1m 扬程时流量可能只剩标称的
三分之一甚至直接不出水。**它很可能带不动这套管路。**

**建议**：

1. 你原清单里的 **365 12V 隔膜泵还在的话，主循环还是用它**
2. 小潜水泵可以留一个做**罐内搅拌** —— 让冰袋周围的冷水混匀，
   避免冷水沉底、温水浮在上面，实际上能提高换热效率。这是个正经用途
3. 剩下的退货或者留作他用

### ❌ R14：密封圈买成了「花洒平垫」

订单原文：`泰姆仕 硅胶密封圈 白色硅胶4分+6分各10个`

4 分 = 1/2 英寸 ≈ 12.7mm，6 分 = 3/4 ≈ 19mm。这是**热水器 / 花洒软管接口的平垫圈**，
内径通常是 14mm / 20mm 上下，**不是 M12 穿板接头用的**。

M12 螺纹外径只有 12mm，14mm 内径的垫圈套上去是松的，压不实。

**先做这一步**：拆开 R15 的穿板接头，看**包装里有没有自带螺母和密封圈**。
多数穿板接头是配齐的，如果配了就不用另外买。

如果确实没有，要买的是两样 —— **它们干的不是一件事**：

| 件 | 尺寸 | 作用 |
|---|---|---|
| 硅胶 O 型圈 | 内径约 11mm × 线径 2mm | **密封**（弹性变形填缝） |
| 尼龙平垫 | 内径 12.5mm × 外径 18mm | **承力**（分散螺母压力，保护 1.5mm 薄壁 PET） |

叠法：`宝塔头法兰 -> 硅胶圈 -> PET罐壁 -> 尼龙平垫 -> 螺母`

**尼龙是硬的，压不出形变，不能当密封件用。**
反过来硅胶太软，单独上容易被螺母挤出来，所以两个一起用最稳。

另外纠正一个我上一条说错的点：**4 分 / 6 分不是螺纹直径，是管子内径的俗称。**
4 分（1/2"）的实际螺纹外径是 **20.955mm**，6 分（3/4"）是 **26.441mm**。
所以你那包垫圈是给 21mm / 26mm 的螺纹配的，M12 只有 12mm —— 差了一倍多。

买之前**用卡尺量一下宝塔头螺纹的实际外径**（标称 M12，实测常在 11.8~12.2 之间）。

---

## 三、要确认的

### ⚠️ R10：12V 锂电池组**是否自带 BMS 保护板**

订单写的是「可充电 12V 锂电池组 带接头送转换头」。
如果电池组内部没有保护板，3S 放到 9V 以下电芯会永久损伤，而 DC-DC 模块不会帮你关断。

**确认方法**：看商品详情有没有「保护板 / BMS / 过充过放过流保护」字样。
没有的话补一块 `3S 12V 40A 同口带均衡 锂电池保护板`（约 12 元）。

### ⚠️ R11：DC 电源模块是「多路输出」，不是两路独立

订单原文：`DC电源模块 3.3V 5V 12V 多路输出 12V转3.3V 5V 12V（大芯片-带保护）`

我原来的方案是**两个独立的 12V→5V 降压模块**（XL4015 供继电器、MP1584EN 供主控），
目的是让泵的大电流不污染主控的电源。多路输出模块是另一种思路，**能不能用取决于每路的电流能力**。

**要查的参数**：

| 参数 | 需要满足 |
|---|---|
| 5V 路输出电流 | **>= 2A**（继电器模块 + ESP32） |
| 3.3V 路输出电流 | >= 500mA（如果要用它直供 3V3） |
| 各路是否共地 | 必须共地 |

另外这类模块的 3.3V 路**很多是 LDO 从 5V 降下来的**，效率低、发热大。
更稳的做法还是：**从模块的 5V 输出接 ESP32 开发板的 5V/VIN 脚**，
让开发板自己的 LDO 去产生 3.3V —— 不要动 3V3 脚。

### ⚠️ R12：冰袋 100mL 偏小

100mL × 50 个 = 总容量 5L，**总量是够的**。但单袋只有 100g，
要凑够我估算用的 500g 有效冰量，得一次放 **5 个**。
小袋的好处是贴合罐体形状、融化均匀；坏处是表面积/体积比大，**融化速度比大袋快**。

对策：一次多放几个（8~10 个），并且**冻透**（-5°C 以下再拿出来）。
半冻的冰袋潜热少一大半。

### ⚠️ R17：TEC1-12712 ×5 用不上

见 `docs/UPGRADE-PLAN.md` 的算账：5 片 TEC 在 12V 下要 **50A / 600W**，
热端要排掉 1300W，你现有的 10A 继电器直接烧毁，电池组撑不过 10 分钟。
留着做台式实验或者别的用途。

---

## 四、还没买的（按优先级）

### 必须补 —— 安全项，缺了不能上身

| 项目 | 型号 | 数量 | 参考价 | 搜索关键词 |
|---|---|---|---|---|
| **DS18B20 防水探头** | 不锈钢封装，带 1m 线 | 5 | 25 元 | `DS18B20 防水探头 不锈钢 1米线` |
| **保险丝座 + 保险丝** | 小号插片保险丝座 + 5A 快熔 | 1 套 | 7 元 | `小号插片保险丝座 带线 5A 快熔` |
| **肩带总电源开关** | KCD1-101 船型开关 2脚2档 >=10A（**不是 22mm 蘑菇头**） | 1 | 5 元 | `KCD1-101 船型开关 2脚2档 10A` |
| **M12 硅胶 O 型圈** | 内径约 11mm x 线径 2mm（先确认接头是否自带） | 10 | 5 元 | `硅胶O型圈 内径11mm 线径2mm` |
| **尼龙平垫** | 内径 12.5mm x 外径 18mm（保护 1.5mm 薄壁 PET） | 10 | 5 元 | `尼龙平垫 M12 内径12.5` |
| | | | **约 45 元** | |

### 强烈建议补 —— 关系到能不能安全地自动跑

| 项目 | 型号 | 数量 | 参考价 | 搜索关键词 |
|---|---|---|---|---|
| **水流传感器** | YF-S401（0.3~6 L/min，5880 脉冲/升） | 1 | 25 元 | `YF-S401 水流传感器 8mm` |
| **液位开关** | M10 304 不锈钢浮球开关，**常开 NO** | 1 | 6 元 | `M10 不锈钢浮球开关 常开` |
| **OLED** | 0.96 寸 SSD1306 128×64 I2C 4 针 | 1 | 15 元 | `0.96寸 OLED SSD1306 I2C 12864` |
| **分压电阻** | 2.2k / 20k（电阻包 R06 里已经有） | — | 0 元 | |
| | | | **约 46 元** | |

缺了水流传感器和液位开关，**干转保护只能靠温度间接判断**（固件里的 `DRY_RUN` 兜底逻辑），
灵敏度和可靠性都差一截。而隔膜泵干转几分钟阀片就废了。

### 可选

| 项目 | 型号 | 参考价 |
|---|---|---|
| 贴身段硅胶管 | 6×8mm 食品级硅胶管 5m | 20 元 |
| 变径接头 | 8mm 转 6mm 宝塔变径 | 10 元 |
| 减震海绵 | 5mm 高密度 EVA 泡棉 | 5 元 |
| 防水盒 | IP67 200×120×75 | 20 元 |

---

## 五、下一步怎么做

1. **先拆 R15 的穿板接头**，看有没有自带螺母和密封圈 —— 决定 R14 要不要重买
2. **确认 R10 电池组有没有 BMS** —— 没有就补一块
3. **补买 DS18B20 防水探头 ×5** —— 这是当前最卡脖子的一项，不解决连温度都测不了
4. **确认 365 隔膜泵还在不在** —— 不在的话要么找出来，要么接受小潜水泵 + 短管路的方案
5. 保险丝和肩带电源开关一起下单，凑一次运费

在温度探头到货之前，固件可以用 `pump on` / `pump off` 手动驱动继电器，
先把电源、继电器、泵的桌面测试做完（见 `docs/BRINGUP.md` 第 0~5 步）。

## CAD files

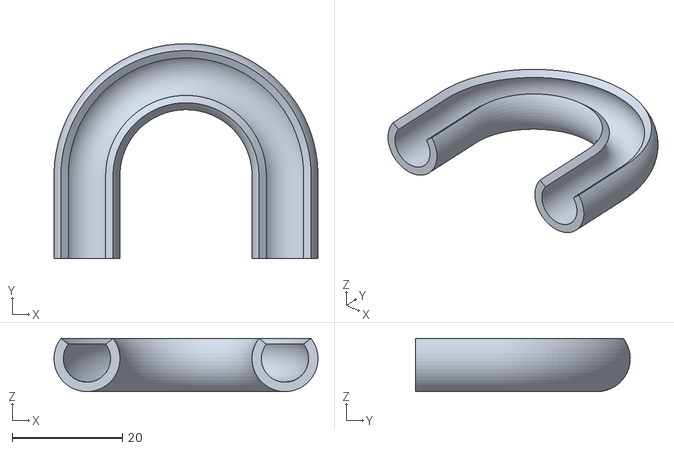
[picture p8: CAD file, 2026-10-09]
projects/body-cooler/cad/bend_180_R18.stl
48.0 x 39.0 x 9.67

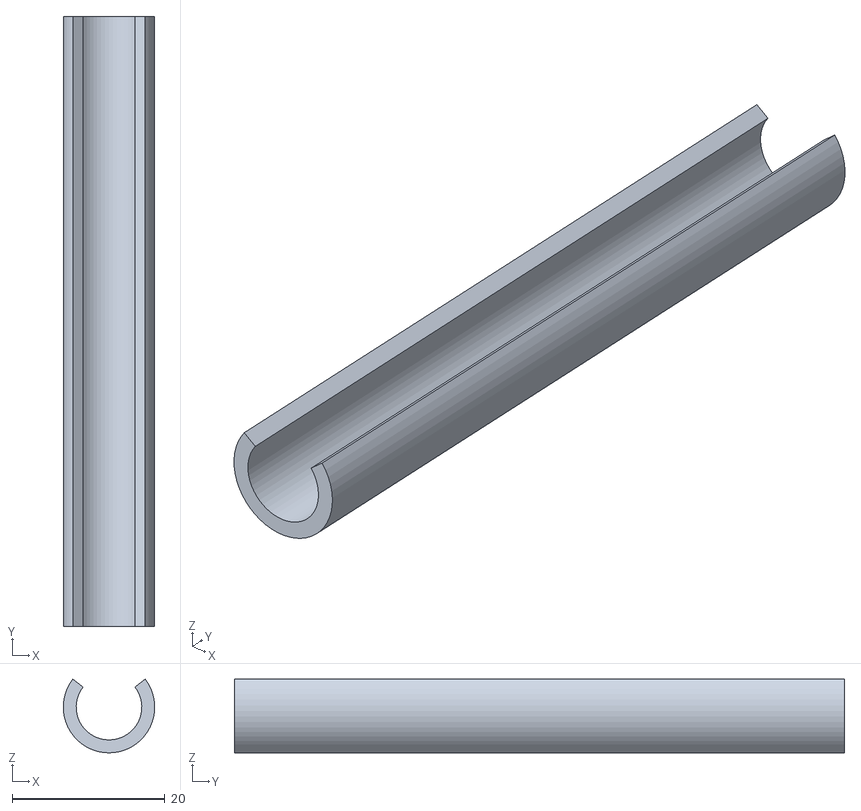
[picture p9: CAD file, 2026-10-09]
projects/body-cooler/cad/straight_80.stl
12.0 x 80.0 x 9.67

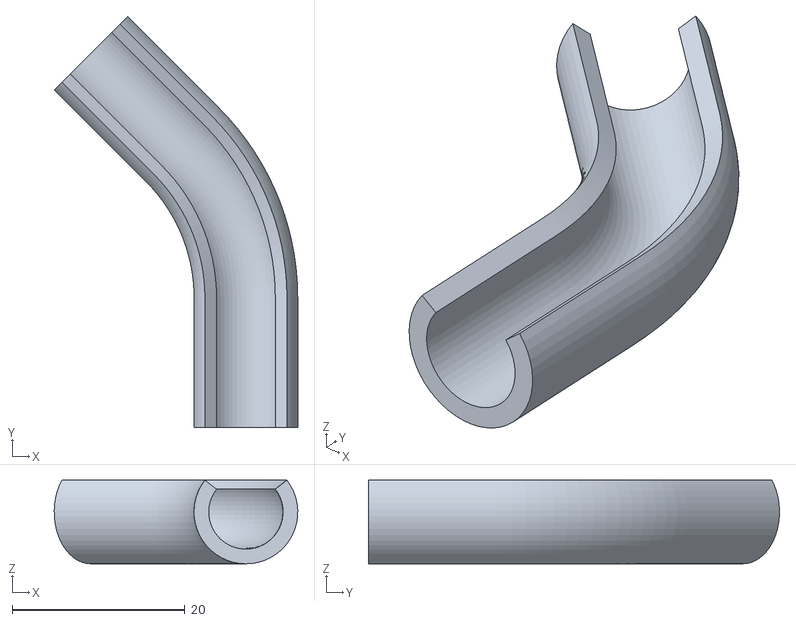
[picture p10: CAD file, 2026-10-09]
projects/body-cooler/cad/bend_45_R25.stl
28.2 x 47.5 x 9.67

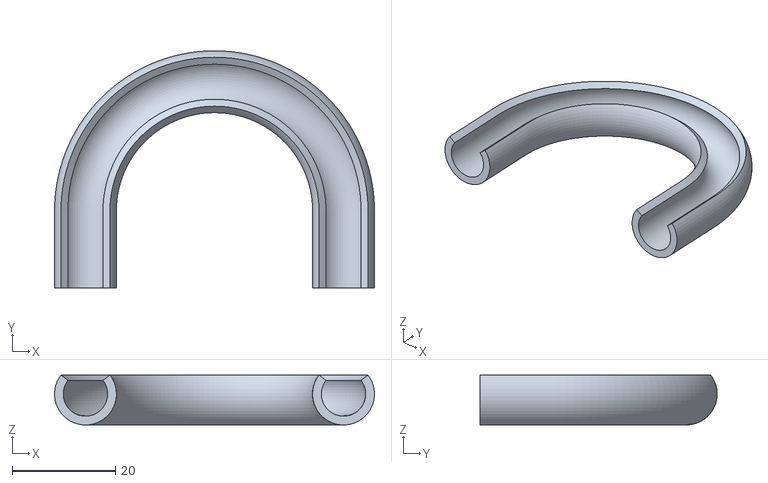
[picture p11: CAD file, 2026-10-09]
projects/body-cooler/cad/bend_180_R25.stl
62.0 x 46.0 x 9.67

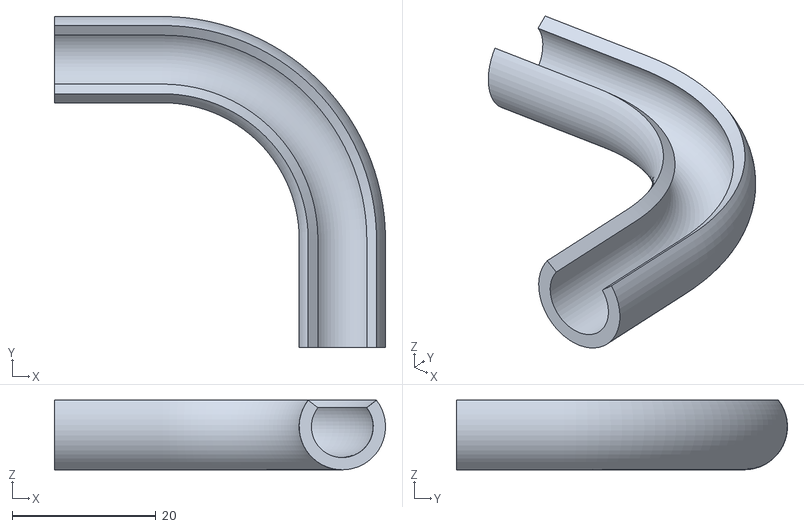
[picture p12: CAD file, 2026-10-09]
projects/body-cooler/cad/bend_90_R25.stl
46.0 x 46.0 x 9.67

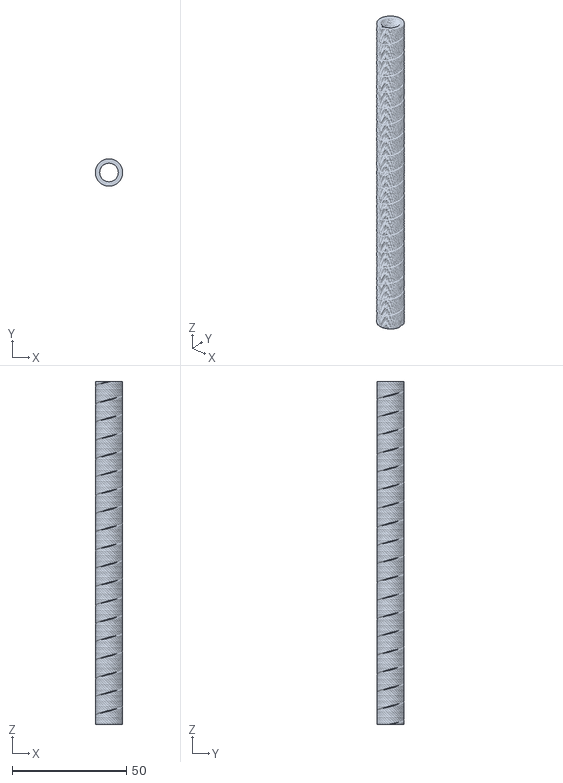
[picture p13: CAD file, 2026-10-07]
projects/body-cooler/cad/sleeve_A_flex.stl
12.0 x 12.0 x 150.0

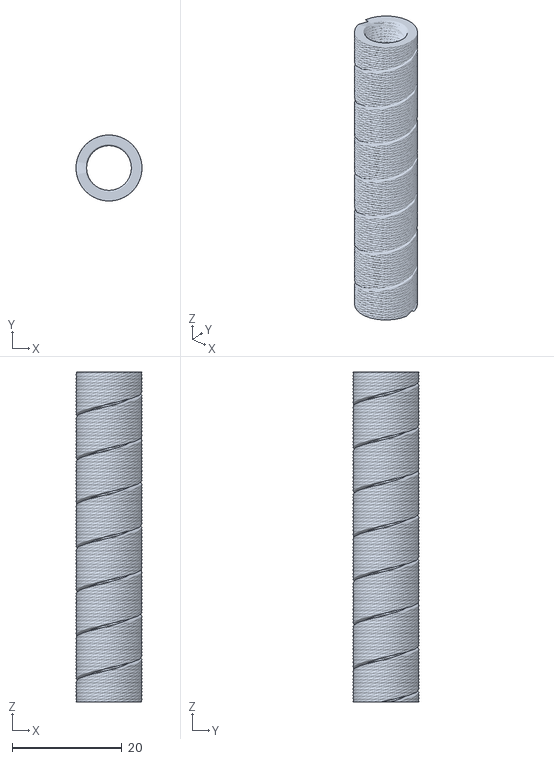
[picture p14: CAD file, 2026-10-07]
projects/body-cooler/cad/sleeve_A_short.stl
12.0 x 12.0 x 60.0

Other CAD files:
projects/body-cooler/cad/sleeve_C_rigid.stl
projects/body-cooler/cad/sleeve_B_mid.stl

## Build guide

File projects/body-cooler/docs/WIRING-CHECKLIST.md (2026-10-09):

# 接线总表 —— 逐触点（照这份文档就能把整机接起来）

> **85 根线，一根一行。** 全部以**物理触点**标识，不用元件上印的字。
> 例如 ESP32 不写 "GPIO5"，写 **`U1 · J1 第 5 脚`**（排针从上往下数）。

## 触点命名约定

| 元件类型 | 怎么写 | 例子 |
|---|---|---|
| ESP32 排针 | `U1 · J1 第 N 脚` / `U1 · J3 第 N 脚`（**从上往下数，第 1 脚在最上面**） | `U1 · J1 第 5 脚` |
| 继电器模块 | `K1 · IN 端子`、`K1 · COM 端子` 等（模块上印的端子名） | `K1 · NO 端子` |
| 降压板 | `PS1 · IN+ 端子`、`PS1 · OUT+ 端子` | `PS1 · OUT+ 端子` |
| 两脚电阻 | `R6 · 脚1` / `R6 · 脚2` —— 电阻不分极性，脚1/脚2 只是本表编号，**照表中"从/到"接即可** | `R6 · 脚1` |
| 二极管 | `D1 · 阳极（无环端）` / `D1 · 阴极（有银环端）` | `D1 · 阴极` |
| 三线传感器 | 按**线色**：`T1 · 红(VDD)`、`T1 · 黑(GND)`、`T1 · 黄(DQ)` | `T1 · 黄(DQ)` |
| 开关/按键 | `SW1 · 触点A` / `SW1 · 触点B`（两只脚不分） | `SW1 · 触点A` |
| 电池/保险丝/泵 | `BT1 · 正极柱`、`F1 · 进线端`/`F1 · 出线端`、`M1 · + 柱`/`M1 · − 柱` | `BT1 · 正极柱` |
| 汇流点 | 直接写母线名：`GND` / `+12V_F` / `5V_A` / `5V_B` / `3V3` | `5V_A` |

---

## 0. 先建 5 条母线（后面所有线都往这 5 点接）

| 母线 | 从哪来 | 供给谁 |
|---|---|---|
| **GND** | `BT1 · 负极柱` | 所有器件的 GND，**必须全部接过来** |
| **+12V_F** | `F1 · 出线端` | 两个降压板的 IN+、5 个继电器的 COM、分压 100k |
| **5V_A** | `PS1 · OUT+(5V) 端子` | 5 个继电器 VCC、5 只 10k、水流传感器 |
| **5V_B** | `PS2 · OUT+(5V) 端子` | **只给 ESP32 的 5V 脚** |
| **3V3** | `PS2 · OUT(3.3V) 端子` | DS18B20 VDD、4.7k 上拉、ESP32 3V3 脚 |

> 继电器线圈吸合瞬间会把 5V 拉出一个坑。ESP32 和继电器**不能共用一条 5V**，否则会复位。

---

## 1. ESP32 逐脚对照表（**先看这张，插线照这个数**）

板上有两排 22 针：`J1` 和 `J3`。**两排都从上往下数，第 1 脚在最上面。**

### J1（22 脚）

| 脚位 | 板上印的字 | 接什么 |
|---|---|---|
| **J1 第 1 脚** | 3V3 | → `3V3` 母线 |
| **J1 第 2 脚** | 3V3 | → `3V3` 母线（与第 1 脚并联） |
| **J1 第 3 脚** | RST | **空** |
| **J1 第 4 脚** | 4 | → `T1 · 黄(DQ)`（D01） |
| **J1 第 5 脚** | 5 | → `K1 · IN 端子`（水泵） |
| **J1 第 6 脚** | 6 | → `K2 · IN 端子` |
| **J1 第 7 脚** | 7 | → `K3 · IN 端子` |
| **J1 第 8 脚** | 15 | → `K4 · IN 端子` |
| **J1 第 9 脚** | 16 | → `K5 · IN 端子` |
| **J1 第 10 脚** | 17 | → `LS1 · + 端`（可选） |
| **J1 第 11 脚** | 18 | → `J1(探针) · 铜线A`（漏水） |
| **J1 第 12 脚** | 8 | **空**（预留 I2C SDA） |
| **J1 第 13 脚** | 3 | **禁用**（strapping） |
| **J1 第 14 脚** | 46 | **禁用**（strapping） |
| **J1 第 15 脚** | 9 | **空**（预留 I2C SCL） |
| **J1 第 16 脚** | 10 | → `R9 · 脚2`（水流分压中点） |
| **J1 第 17 脚** | 11 | → `SW1 · 触点A`（浮子液位） |
| **J1 第 18 脚** | 12 | **空** |
| **J1 第 19 脚** | 13 | **空** |
| **J1 第 20 脚** | 14 | **空** |
| **J1 第 21 脚** | 5V | → `5V_B` 母线 |
| **J1 第 22 脚** | GND | → `GND` 母线 |

### J3（22 脚）

| 脚位 | 板上印的字 | 接什么 |
|---|---|---|
| **J3 第 1 脚** | GND | → `GND` 母线 |
| **J3 第 2 脚** | TX | 板载 CH343 占用，**空** |
| **J3 第 3 脚** | RX | 板载 CH343 占用，**空** |
| **J3 第 4 脚** | 1 | → `R6 · 脚2`（电池分压中点） |
| **J3 第 5 脚** | 2 | **空**（备用 ADC） |
| **J3 第 6 脚** | 42 | **空** |
| **J3 第 7 脚** | 41 | **空** |
| **J3 第 8 脚** | 40 | **空** |
| **J3 第 9 脚** | 39 | → `SW4 · 触点A`（按键B） |
| **J3 第 10 脚** | 38 | → `SW3 · 触点A`（按键A） |
| **J3 第 11 脚** | 37 | **禁用**（OPI PSRAM） |
| **J3 第 12 脚** | 36 | **禁用** |
| **J3 第 13 脚** | 35 | **禁用** |
| **J3 第 14 脚** | 0 | **禁用**（strapping） |
| **J3 第 15 脚** | 45 | **禁用**（strapping） |
| **J3 第 16 脚** | 48 | 板载 WS2812 状态灯，**不接线** |
| **J3 第 17 脚** | 47 | **空** |
| **J3 第 18 脚** | 21 | → `SW2 · COM 端`（急停/总电源，常闭） |
| **J3 第 19 脚** | 20 | **禁用**（原生 USB D+） |
| **J3 第 20 脚** | 19 | **禁用**（原生 USB D−） |
| **J3 第 21 脚** | GND | → `GND` 母线 |
| **J3 第 22 脚** | GND | → `GND` 母线 |

> **`J1 第 5 脚` 到 `J1 第 9 脚` 是连续的 5 个脚**，正好接 5 个继电器的 IN。

---

## 2. 逐根接线表

### A 组：电源（**先接这组，接完先量电压再往下**）

| # | 从（触点） | 到（触点） | 说明 | ☐ |
|---|---|---|---|---|
| **A01** | `BT1 · 正极柱` | `F1 · 进线端` | 电池正极先进保险丝 | ☐ |
| **A02** | `F1 · 出线端` | **`+12V_F`** | 保险丝之后才叫 +12V_F | ☐ |
| **A03** | `BT1 · 负极柱` | **`GND`** | 电池负极 = 系统公共地 | ☐ |
| **A04** | `+12V_F` | `PS1 · IN+ 端子` | 降压板1 输入 | ☐ |
| **A05** | `GND` | `PS1 · IN− 端子` | | ☐ |
| **A06** | `+12V_F` | `PS2 · IN+ 端子` | 降压板2 输入 | ☐ |
| **A07** | `GND` | `PS2 · IN− 端子` | | ☐ |
| **A08** | `PS1 · OUT+(5V)` | **`5V_A`** | 只喂继电器线圈 | ☐ |
| **A09** | `PS2 · OUT+(5V)` | **`5V_B`** | 只喂 ESP32 | ☐ |
| **A10** | `PS2 · OUT(3.3V)` | **`3V3`** | 喂探头和 ESP32 的 3V3 | ☐ |

**停下来量一下**（黑表笔接 GND）：

```
□ 5V_A   对 GND   4.9 ~ 5.1 V
□ 5V_B   对 GND   4.9 ~ 5.1 V
□ 3V3    对 GND   3.25 ~ 3.35 V
□ +12V_F 对 GND   = 电池电压（11 ~ 12.6 V）
□ 断电量 F1 出线端 对 GND 的电阻 —— 不能是 0 欧，否则是短路，别上电
```

> ⚠ **泵绝对不能从降压板取电。** 必须直连电池（经保险丝 + 继电器触点）。上一台泵就这么烧的。

### B 组：泵主回路

| # | 从（触点） | 到（触点） | 说明 | ☐ |
|---|---|---|---|---|
| **B01** | `+12V_F` | `K1 · COM 端子` | 继电器1 公共端 | ☐ |
| **B02** | `K1 · NO 端子` | `M1 · + 柱` | **必须 NO，不能 NC** | ☐ |
| **B03** | `M1 · − 柱` | **`GND`** | 泵负极直回电池负极 | ☐ |
| **B04** | `D1 · 阴极（有银环端）` | `M1 · + 柱` | 与 B02 同一个接点 | ☐ |
| **B05** | `D1 · 阳极（无环端）` | `M1 · − 柱` | 与 B03 同一个接点 | ☐ |

### C 组：控制端

#### C-1 五路继电器（**核心**）

| # | 从（触点） | 到（触点） | 说明 | ☐ |
|---|---|---|---|---|
| **C01** | `U1 · J1 第 5 脚` | `K1 · IN 端子` | 水泵 | ☐ |
| **C02** | `U1 · J1 第 6 脚` | `K2 · IN 端子` | | ☐ |
| **C03** | `U1 · J1 第 7 脚` | `K3 · IN 端子` | | ☐ |
| **C04** | `U1 · J1 第 8 脚` | `K4 · IN 端子` | | ☐ |
| **C05** | `U1 · J1 第 9 脚` | `K5 · IN 端子` | | ☐ |
| **C06** | `5V_A` | `K1 · VCC 端子` | | ☐ |
| **C07** | `GND` | `K1 · GND 端子` | | ☐ |
| **C08** | `5V_A` | `K2 · VCC 端子` | | ☐ |
| **C09** | `GND` | `K2 · GND 端子` | | ☐ |
| **C10** | `5V_A` | `K3 · VCC 端子` | | ☐ |
| **C11** | `GND` | `K3 · GND 端子` | | ☐ |
| **C12** | `5V_A` | `K4 · VCC 端子` | | ☐ |
| **C13** | `GND` | `K4 · GND 端子` | | ☐ |
| **C14** | `5V_A` | `K5 · VCC 端子` | | ☐ |
| **C15** | `GND` | `K5 · GND 端子` | | ☐ |

> K1~K5 的 **`NC 端子` 全部不接**；K2~K5 的 **`NO 端子` 留空**（备用继电器）。

#### C-2 五只 10k 上拉（最容易漏）

| # | 从（触点） | 到（触点） | 说明 | ☐ |
|---|---|---|---|---|
| **C16** | `R1 · 脚1` | `5V_A` | | ☐ |
| **C17** | `R1 · 脚2` | `K1 · IN 端子` | 与 C01 同一个接点 | ☐ |
| **C18** | `R2 · 脚1` | `5V_A` | | ☐ |
| **C19** | `R2 · 脚2` | `K2 · IN 端子` | 与 C02 同一个接点 | ☐ |
| **C20** | `R3 · 脚1` | `5V_A` | | ☐ |
| **C21** | `R3 · 脚2` | `K3 · IN 端子` | 与 C03 同一个接点 | ☐ |
| **C22** | `R4 · 脚1` | `5V_A` | | ☐ |
| **C23** | `R4 · 脚2` | `K4 · IN 端子` | 与 C04 同一个接点 | ☐ |
| **C24** | `R5 · 脚1` | `5V_A` | | ☐ |
| **C25** | `R5 · 脚2` | `K5 · IN 端子` | 与 C05 同一个接点 | ☐ |

> ESP32 复位那几百毫秒里 GPIO 是高阻（悬空）。悬空的 `IN` 会被水泵电刷干扰带偏，继电器乱吸合。
> 这只 10k 把悬空状态明确拉到 5V。**必须上拉到 5V**（模块是低电平触发），不是下拉到 GND。

#### C-3 蜂鸣器 + ESP32 供电

| # | 从（触点） | 到（触点） | 说明 | ☐ |
|---|---|---|---|---|
| **C26** | `U1 · J1 第 10 脚` | `LS1 · + 端` | 可选 | ☐ |
| **C27** | `LS1 · − 端` | **`GND`** | | ☐ |
| **C28** | `U1 · J1 第 21 脚` | **`5V_B`** | ★ 是 5V 脚，不是 3V3 脚 | ☐ |
| **C29** | `U1 · J1 第 1 脚` | **`3V3`** | | ☐ |
| **C30** | `U1 · J1 第 22 脚` | **`GND`** | ★ 少这一根，改什么极性都没用 | ☐ |

### D 组：输入端

#### D-1 DS18B20 单总线（5 个探头并联）

| # | 从（触点） | 到（触点） | 说明 | ☐ |
|---|---|---|---|---|
| **D01** | `U1 · J1 第 4 脚` | `T1 · 黄(DQ)` | 总线起点 | ☐ |
| **D02** | `T1 · 黄(DQ)` | `T2 · 黄(DQ)` | 并联 | ☐ |
| **D03** | `T2 · 黄(DQ)` | `T3 · 黄(DQ)` | 并联 | ☐ |
| **D04** | `T3 · 黄(DQ)` | `T4 · 黄(DQ)` | 探头还没到货 | ☐ |
| **D05** | `T4 · 黄(DQ)` | `T5 · 黄(DQ)` | 探头还没到货 | ☐ |
| **D06** | **`3V3`** | `R11 · 脚1` | 整条总线只加这一只 4.7k | ☐ |
| **D07** | `R11 · 脚2` | `T1 · 黄(DQ)` | 与 D01 同一个接点 | ☐ |
| **D08** | **`3V3`** | `T1 · 红(VDD)` | | ☐ |
| **D09** | **`GND`** | `T1 · 黑(GND)` | | ☐ |
| **D10** | **`3V3`** | `T2 · 红(VDD)` | | ☐ |
| **D11** | **`GND`** | `T2 · 黑(GND)` | | ☐ |
| **D12** | **`3V3`** | `T3 · 红(VDD)` | | ☐ |
| **D13** | **`GND`** | `T3 · 黑(GND)` | | ☐ |
| **D14** | **`3V3`** | `T4 · 红(VDD)` | 探头还没到货 | ☐ |
| **D15** | **`GND`** | `T4 · 黑(GND)` | 探头还没到货 | ☐ |
| **D16** | **`3V3`** | `T5 · 红(VDD)` | 探头还没到货 | ☐ |
| **D17** | **`GND`** | `T5 · 黑(GND)` | 探头还没到货 | ☐ |

> 4.7k **必须拉到 3V3，不能拉到 5V**，否则打坏 `J1 第 4 脚`。

#### D-2 电池电压采样

| # | 从（触点） | 到（触点） | 说明 | ☐ |
|---|---|---|---|---|
| **D18** | **`+12V_F`** | `R6 · 脚1` | 100k | ☐ |
| **D19** | `R6 · 脚2` | `R7 · 脚1` | ★ 这个中点接 ADC | ☐ |
| **D20** | `R6 · 脚2` | `U1 · J3 第 4 脚` | 与 D19 同一个接点 | ☐ |
| **D21** | `R7 · 脚2` | **`GND`** | 18k | ☐ |

#### D-3 水流传感器

| # | 从（触点） | 到（触点） | 说明 | ☐ |
|---|---|---|---|---|
| **D22** | **`5V_A`** | `FS1 · 红(VCC)` | | ☐ |
| **D23** | **`GND`** | `FS1 · 黑(GND)` | | ☐ |
| **D24** | **`5V_A`** | `R8 · 脚1` | 2.2k | ☐ |
| **D25** | `R8 · 脚2` | `FS1 · 黄(OUT)` | ★ 这个接点叫 FLOW_PU | ☐ |
| **D26** | `FS1 · 黄(OUT)` | `R9 · 脚1` | 与 D25 同一个接点 | ☐ |
| **D27** | `R9 · 脚2` | `U1 · J1 第 16 脚` | ★ 中点进 ADC | ☐ |
| **D28** | `R9 · 脚2` | `R10 · 脚1` | 与 D27 同一个接点 | ☐ |
| **D29** | `R10 · 脚2` | **`GND`** | 20k | ☐ |

#### D-4 开关量（都是「引脚 — 开关 — GND」）

| # | 从（触点） | 到（触点） | 说明 | ☐ |
|---|---|---|---|---|
| **D30** | `U1 · J1 第 17 脚` | `SW1 · 触点A` | 浮子液位（常开） | ☐ |
| **D31** | `SW1 · 触点B` | **`GND`** | | ☐ |
| **D32** | `U1 · J1 第 11 脚` | `J2 · 铜线A` | 漏水探针 | ☐ |
| **D33** | `J2 · 铜线B` | **`GND`** | 两线相距 2~3mm | ☐ |
| **D34** | `U1 · J3 第 18 脚` | `SW2 · COM 端` | 急停/总电源（**常闭**） | ☐ |
| **D35** | `SW2 · NC 端` | **`GND`** | | ☐ |
| **D36** | `U1 · J3 第 10 脚` | `SW3 · 触点A` | 按键 A（固件暂未用） | ☐ |
| **D37** | `SW3 · 触点B` | **`GND`** | | ☐ |
| **D38** | `U1 · J3 第 9 脚` | `SW4 · 触点A` | 按键 B（固件暂未用） | ☐ |
| **D39** | `SW4 · 触点B` | **`GND`** | | ☐ |

> **SW2 用常闭**：「按下」和「线断了」是同一种结果 —— 失效安全。
> **建议**：把 SW2 的另一组触点串进 B01 那条线（泵的 12V 硬回路），MCU 死机也能物理切泵。

### E 组：调试串口

| # | 从 | 到 | 说明 | ☐ |
|---|---|---|---|---|
| **E01** | 电脑 USB 口 | `U1` 上印 **`USB`** 的那个 USB-C 座 | 控制台和烧录都走这个口 | ☐ |

---

## 3. 上电前 10 条检查

```
□  1. 泵的 12V 是从电池来的吗？中间只有保险丝和 K1 的 COM/NO？
□  2. 保险丝装在电池正极分流之前了吗？
□  3. D1 阴极（有银环端）朝 M1 的 + 柱吗？
□  4. K1 用的是 COM + NO，不是 NC 吗？
□  5. K1~K5 的 IN 都各有一只 10k 上拉到 5V_A 吗？（5 只）
□  6. U1 的 J1 第 22 脚（GND）和继电器模块的 GND 是同一个点吗？
□  7. U1 的 J1 第 21 脚（5V）接的是 5V_B，不是 3V3 吗？
□  8. 断电量 F1 出线端 对 GND 的电阻 —— 不能是 0 欧。
□  9. 泵放水里了吗？
□ 10. 手放在电池接头上，闻到糊味立刻断。
```

---

## 4. 最容易接错的 8 处

| # | 错在哪 | 症状 | 怎么查 |
|---|---|---|---|
| 1 | 漏了 **C30**（ESP32 GND） | 说 `pump=ON` 不吸合；说 `pump=OFF` 反而一直转 | 通断档量 J1 第 22 脚 和模块 GND，必须 0Ω |
| 2 | 10k 漏了或接成下拉 | 复位/烧录时泵自己抽一下 | 每只 IN 到 5V_A 之间必须有 10k |
| 3 | **D1 装反** | 一上电就烧保险丝 | 有银环那端朝 M1 的 + 柱 |
| 4 | 继电器用了 **NC 触点** | 断电时泵反而在转 | 换到 COM + NO |
| 5 | 泵从降压板取电 | 降压板冒烟、泵欠压堵转 | 泵 12V 直连电池 |
| 6 | 4.7k 上拉到 5V | J1 第 4 脚被打坏 | 必须拉到 3V3 |
| 7 | **排针数错一格** | 全乱 | 照第 1 节的逐脚表，**从最上面那个脚开始数** |
| 8 | 5V_A 和 5V_B 并成一条 | 继电器一吸合 ESP32 就复位 | 两条独立的 5V |

---

## 5. 接完之后的验证步骤

```
# 1. 只接电池 + 降压板，不接 ESP32：量 5V_A / 5V_B / 3V3 都对
# 2. 接 ESP32（USB 线先别插），上电，看板载灯
# 3. 插 USB 线（USB 那个口），开串口 115200：

scan                       # 应列出 5 个探头 ROM
map skin_chest 0           # 把 1 号探头绑成"胸前体表"（自动存 NVS）
relay test                 # 每 5 秒翻一次 IN，用耳朵确认哪次咔哒
pump on                    # 强制开泵
pump off                   # 应该真的停 —— 停了才说明驱动方式对
enable on                  # 打开自动控温
status                     # reason 行会直接告诉你为什么开/不开
```

---

## 6. 相关文档

| 文档 | 内容 |
|---|---|
| `BENCH-TEST.md` | 台架测试、事故记录、上电前检查 |
| `WIRING-GUIDE.md` | 电路原理（为什么这么接） |
| `GPIO-MAP.md` | GPIO 映射与禁用脚说明 |
| `SEALING-REVIEW.md` | 密封、冷凝、软管被吸瘪的排查 |
| `../cad/README.md` | 3D 打印件：防折护套 + 转角导弯件 |

> 本表不含任何陶瓷电容与电解电容（按要求去掉）。
> 如果实测出现 ESP32 复位，第一个补的是 5V 轨上的电解电容。

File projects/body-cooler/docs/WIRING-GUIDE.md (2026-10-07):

# 接线总览与电路原理

## 怎么看这些图（图例）

### 图上的圆圈数字是什么

**不是元件编号**，分两种：

| 编号 | 出现在 | 含义 |
|---|---|---|
| 大圆圈 **①②③** | 图 4、图 6 | **分区 / 步骤编号**，纯排版用 |
| **X1-1 ~ X1-8** | 图 6 | **端子位号**：X1 号端子排的第 1 格螺钉 |
| **X2-1 ~ X2-20** | 图 6 | **端子位号**：X2 号端子排的第 1 格螺钉 |

> **X1-1 和 X2-1 是两个完全不同的端子**，别接混。

### 实心小黑点

导线交叉或分支处的**实心小圆点 = 电气连接点**，表示这几根线在这里是连通的。

**没有黑点的交叉 = 两根线只是画面上交叉，实际不相连。** 这是电路图的通用约定。

### 元件位号的正规规则

工程图上真正的元件位号是**字母前缀 + 数字**（GB/T 5094 / IEC 61346）：

| 前缀 | 类别 | 本项目例子 |
|---|---|---|
| X | 端子排 / 连接器 | X1 电源端子排、X2 引脚端子排 |
| R | 电阻 | R1 100k、R2 18k |
| C | 电容 | C1 100nF |
| D | 二极管 | D1 1N5822 续流二极管 |
| K | 继电器 | K1 水泵继电器 |
| M | 电动机 | M1 365 泵 |
| FU | 熔断器 | FU1 5A 保险丝 |
| S | 开关 | S1 肩带开关 |
| BT | 电池 | BT1 3S 锂电组 |
| U | 集成电路 | U1 ESP32-S3 |
| T | 电源模块 | T1 DC-DC #1 |

字母 = 类别，数字 = 同类里的第几个。本项目的图里**没有用元件位号**，
因为元件少（十几个），值都直接标在旁边了（100k、4.7k…）。

---

配套图纸：

| 图 | 文件 | 内容 |
|---|---|---|
| 图 1 | `docs/diagrams/fig1_power_pump.png` | 电源分配与水泵主回路 |
| 图 2 | `docs/diagrams/fig2_esp32_wiring.png` | ESP32-S3 全部引脚接线 |
| 图 3 | `docs/diagrams/fig3_water_loop.png` | 水路走向与保温结构 |

---

# 第一层：电源树

```
3S 锂电池组 (11.1V 标称 / 12.6V 满)
   |
   +-- 5A 快熔保险丝          <- 必须在分流之前
   |
   +-- +12V 母线
         |
         +-- 急停常闭触点 -> 继电器 COM/NO -> 365 泵      (主回路，大电流)
         |
         +-- DC-DC #1 (XL4015E1) -> 5V_A -> 继电器模块 VCC
         |
         +-- DC-DC #2 (MP1584EN) -> 5V_B -> ESP32 + 传感器
                                                   |
                                    开发板自带 LDO -> 3V3 -> 探头

电池负极 ------------------------------ GND 母线（所有模块单点共地）
```

**为什么要两个 DC-DC 分开？**

泵是**有刷电机**，启动瞬间电流是额定的 3~5 倍（0.45A × 4 ≈ **2A**）。
这一下会把 12V 母线拽下去，同时叠加上电机电刷打火产生的高频尖峰。
如果 ESP32 和泵共用一路 5V，这个尖峰就会顺着电源进到单片机里 ——
表现是**跑着跑着自己复位**，而且很难查。分开之后，ESP32 看到的是干净电源。

**为什么从 DC-DC 的 5V 接开发板的 5V 脚，而不是接 3V3 脚？**

开发板上自己有一颗 LDO 负责 5V 到 3.3V。从 5V 脚进，等于复用了它；
直接往 3V3 脚灌 3.3V 会绕过这颗 LDO，而且 USB 一插就和板载 LDO 打架。

---

# 第二层：主回路（泵怎么被开关）

```
电池+ --[保险丝]--[急停 常闭]--+
                              |
                       继电器 COM
                              |
                         (触点/线圈)
                              |
                       继电器 NO --+-- 泵 +
                                   |
                            [续流二极管]   (反向并联，阴极朝左)
                                   |
                        泵 - ------+-- 电池-
```

## 三个关键点

### 1. 为什么用 NO（常开）而不是 NC

NO 的意思是「线圈不通电时，触点是断开的」。
这样**一旦断电、单片机死机、线掉了，泵自动停**。这是失效安全。
用 NC 的话断电时泵反而在转，背在身上就是事故。

### 2. 为什么把继电器放在正极侧（高边开关）

泵的负极直接回电池负极（也就是公共地），正极走继电器。
另一种做法是负极侧开关（低边），但那样泵的正极永远带电，
在潮湿环境里不如正极受控来得干净。

### 3. 续流二极管 —— 这一条不做会烧继电器

泵是**有刷直流电机，本质是个大电感**。电感里的电流不能突变。
继电器触点断开的瞬间，线圈里的电流被硬生生切断，
根据 U = -L·di/dt，di/dt 极大，于是产生**几百伏的反向电压尖峰**。

后果有两个：

* 触点之间**拉弧**。标称 10A 是**阻性负载**的额定值，感性负载要打对折甚至更多。
  触点会慢慢烧出麻点，用几个月后出现「继电器咔哒响但泵不转」（接触电阻变大）
* 尖峰顺着 12V 母线往回灌，通过 DC-DC 耦合到 3.3V，把 ESP32 打复位

**接法**：二极管**反向并联在泵的两个接线端子上**，
**阴极（有环 / 有银条的那一端）接 +12V 侧**。
正常工作时它反偏截止、不导通；断开瞬间它给电机电流提供一条续流回路，
把尖峰钳在 0.4V（肖特基）左右。

> **接反 = 直接把 12V 电源短路**，会瞬间烧保险丝。装之前用万用表二极管档确认方向。

---

# 第三层：控制回路（ESP32 怎么让泵转）

```
ESP32 GPIO5 ----> 继电器模块 IN
                   (模块内部: IN -> 光耦 LED -> 光耦三极管 -> 驱动三极管 -> 线圈)
5V_A -----------> 继电器模块 VCC
GND ------------> 继电器模块 GND
```

**继电器模块为什么必须 5V 供电，但 3.3V 信号也能用？**

模块里是「光耦 + 三极管 + 5V 线圈」。线圈是 5V 的，所以 VCC 必须给 5V。
但 IN 引脚后面接的是光耦的 LED，串了限流电阻 ——
3.3V 时电流约 (3.3 - 1.2) / 1000 ≈ 2.1mA，处在光耦的可用区间。
所以 3.3V 信号能驱动。不过不同批次模块限流电阻不一样，**一定要实测**。

**上电瞬间的坑：**

ESP32 复位期间 GPIO 是**高阻输入**（既不输出高也不输出低），
继电器 IN 引脚等于**悬空**。如果模块是高电平触发，IN 悬空可能被拉高，**上电泵就转**。

固件里已经做了防护（先写输出电平、再切成 OUTPUT），
但那只覆盖初始化之后。**从复位到初始化之间还有几百毫秒固件管不到**，
只能靠外部电阻兜住：

* 高电平触发模块：IN 到 GND 接 **10kΩ 下拉**
* 低电平触发模块：IN 到 5V 接 **10kΩ 上拉**

5 个继电器模块，每个 IN 都要加。

---

# 第四层：传感器

## DS18B20：一根线怎么接 5 个探头

```
3V3 --[4.7k]--+---------------------------- GPIO4
              |
            +-+-+-----+-----+-----+
          [探头1][探头2][探头3][探头4][探头5]      5 个全部并联
            +---+-----+-----+-----+
              |
             GND
```

**单总线（1-Wire）的原理**：一根数据线既传命令又传数据，还兼做供电时序。
总线是**开漏**的，所以必须有一个上拉电阻把线拉高，靠 4.7k 提供。

* 每个 DS18B20 出厂有**全球唯一的 64 位 ROM 地址**，主机先发 ROM 地址再读写，
  所以一条总线上挂多少个都不会串号。
* **整条总线只允许一个上拉电阻。** 5 个探头各带一个 4.7k 就是 940Ω，太低。
* 上拉必须接 **3V3 不是 5V** —— ESP32-S3 的 IO 不是 5V 耐受的，会烧脚。

固件里通过 ROM 地址把探头绑定到角色（map 命令），存进 NVS，掉电不丢。
这样即使探头上电顺序变了也不会串角色。

## 电池电压采样：分压 + ADC

```
BAT+ 12.6V --[R1 100k]--+-- GPIO1 (ADC1_CH0)
                        |
                      [R2 18k]  || 100nF
                        |
                       GND

分压比 = (100 + 18) / 18 = 6.556
12.6V -> 1.92V     9.0V -> 1.37V
```

三个要点：

1. **分压比要算准**。ESP32 引脚绝对最大电压是 VDD + 0.3 = 3.6V。
   12.6V 直接进引脚就是烧。分压后 1.92V，留了足够余量。
2. **必须用 ADC1（GPIO1~10）**。ESP32-S3 有两组 ADC，
   **ADC2（GPIO11~20）在 WiFi 开启时不可用**（被射频占用）。
   虽然现在没开 WiFi，但升级路线里有手机端，先把线接对省得返工。
3. **R2 上并 100nF**。100k / 18k 的并联阻抗约 15k，对 ESP32 的 ADC 偏高，
   采样时会因为内部采样电容充电不足而读数偏低。这颗电容给采样提供本地电荷池。

固件用 analogReadMilliVolts() 而不是 analogRead() —— 前者会读 eFuse 里的
出厂校准值，比 analogRead() * 3.3 / 4095 准得多。

## 水流传感器：5V 方波怎么进 3.3V 的引脚

```
5V --[2.2k]--+-- 传感器 OUT
             |
           [10k] R1
             |
             +-------- GPIO10
             |
           [20k] R2
             |
            GND

GPIO 高电平 = 5 x R2 / (Rpu + R1 + R2) = 5 x 20 / (2.2 + 10 + 20) = 3.11V
```

**那只 2.2k 不能省。** 分压电阻本身就是个负载，会把高电平往下拽：

| 上拉情况 | 送到 GPIO 的高电平 | 结果 |
|---|---|---|
| 自加 2.2k + 10k/20k | 3.11 V | 稳 |
| 只有传感器内部 10k + 10k/20k | 2.50 V | 贴着门限，危险 |
| 只有传感器内部 10k + 10k/15k | 2.14 V | **低于门限，认不出高电平** |

ESP32-S3 的输入高电平门限 V_IH = 0.75 × 3.3 = **2.475V**。
接好后用万用表实测 GPIO10 对 GND 的高电平，**要在 2.8V 以上**。

## 开关量输入：液位 / 急停 / 漏水 / 按键

这四个都用 **MCU 内部上拉**，一端接引脚、一端接 GND：

| 信号 | 接法 | 有效状态 |
|---|---|---|
| 液位开关（浮子，常开 NO） | 引脚 — 开关 — GND | 低 = 有水 |
| 漏水检测（两根裸铜线） | 引脚 — 裸铜线A — 约2mm间隙 — 裸铜线B — GND | 低 = 遇水 |
| 急停按钮（**常闭 NC**） | 引脚 — 按钮 — GND | **高 = 按下或线断** |
| 按键 A / B | 引脚 — 轻触开关 — GND | 低 = 按下 |

**急停为什么用常闭？**

不按时触点闭合到 GND，引脚读低；按下时断开，被上拉拉高。
这样**「按下」和「线断了」是同一种结果** —— 失效安全。
常开的话线断了没人知道，急停就形同虚设。

软件急停依赖单片机活着。**强烈建议把按钮的另一组触点串在泵的 12V 硬回路里**，
这样即使单片机死机，按下去也能物理切断。

---

# 第五层：这几层怎么配合工作

```
DS18B20 每 ~2 秒采一次 5 个温度
        |
        v
PumpController 每 500ms 判决一次：

   1) 安全联锁（可以打断最短运行时间，立即停泵）
      漏水 / 急停 / 液位低 / 电池电压低 / 水温过低 / 读数全废
        |
   2) 最短运行 20s、最短停机 30s（保护触点与泵阀片）
        |
   3) 需求判定：体表温度 >= 目标+回差/2 -> 开泵
                体表温度 <= 目标-回差/2 -> 停泵
        |
        v
GPIO5 -> 继电器 -> 泵
```

**为什么不能 PWM 调速？**

有刷电机的换向器和电刷在 PWM 下会剧烈打火、发热、噪音大；
隔膜泵在低速下流量急剧下降、阀片拍打异常。
所以只能整段开、整段关，靠**时间比例**模拟调速 ——
一个开关周期是几十秒到几分钟，远大于电机的热时间常数，
电机每次都按额定转速工作，没有任何副作用。

---

# 上电顺序（别跳步）

1. **不接泵**，只上 ESP32 → 看启动横幅、确认 16MB flash / 8MB PSRAM
2. 接 1 个 DS18B20 + 4.7k → `scan`，丢进冰水混合物校准到 0°C
3. 接齐 5 个 → `map` 绑定角色 → `save`
4. **只测继电器模块（不接泵）** → `aux 1 on` / `aux 1 off`
   按住 RST 复位 20 次，确认泵不会误抽 → 决定要不要加 10k
5. 接泵（先不接水，每次通电 ≤3 秒）→ 测干扰，看串口丢不丢字符
6. 加水循环 30 分钟 → 测密封和渗漏
7. 用水杯模拟温度做控温闭环测试
8. 最后才上身

完整验收标准见 `docs/BRINGUP.md`。

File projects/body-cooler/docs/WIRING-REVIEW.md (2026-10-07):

# 接线与电源审查

> 结论先说：**大方向全对**（高边开关、NO 触点、5V 供电的继电器、4.7k 上拉、12V 降压给 ESP32）。
> 但有 **6 处必须改**，否则轻则继电器触点几个月就烧黑、重则 ESP32 被电机尖峰打复位。

---

## 一、你给的原方案，逐条核对

| 你的接法 | 判定 | 说明 |
|---|---|---|
| 12V 电池正极 → 继电器 COM | 正确 | 高边开关，正确 |
| 继电器 NO → 泵正极 | 正确 | 用 **NO**（常开）而不是 NC，断电时泵不转，正确 |
| 泵负极 → 12V 负极 | 正确 | 正确 |
| 12V → DC-DC 降压 → 5V → ESP32 + 继电器 VCC | 需改 | 方向对，但**不能让 ESP32 和 5 个继电器共用同一条细线**，见问题 4 |
| ESP32 GPIO → 继电器 IN | 需改 | 电平兼容没问题，但**上电瞬间必须有外部电阻兜底**，见问题 2 |
| DS18B20 数据线加 4.7kΩ 上拉 | 正确 | 5 个探头并联一条总线没问题 |

---

## 二、必须改的 6 处

### 1. 【最要紧】泵两端加续流二极管

365 泵是**有刷直流电机**，本质是一个大电感。继电器断开瞬间，线圈里的电流被硬切断，
会产生几百伏的反向尖峰：

* 继电器触点之间**拉弧** —— 标称 10A 是**阻性负载**额定值，感性负载通常要打到 5 折甚至更低。
  你这个 0.45A 的泵电流不大，但 12V 感性负载拉弧会慢慢把触点烧出麻点和凹坑，
  典型表现是用了几个月之后继电器咔哒响但泵不转（触点接触电阻变大）。
* 尖峰顺着 12V 母线往回流，通过 DC-DC 耦合到 3.3V，**让 ESP32 复位或 1-Wire 时序错乱**。

**做法**：一只二极管**反向并联在泵的两个接线端子上**（阴极 = 有环的那一端，接 +12V 侧）。

* 型号：**1N5408**（3A / 1000V，便宜大碗）或 **SS34 / 1N5822**（肖特基，压降更低）。
* 方向千万别装反 —— 反了就是**直接把 12V 电源短路**，会立刻烧保险丝。
* 二极管**尽量靠近泵**，引线越短越好（引线本身也是天线）。

这一块钱的东西解决 90% 的「电机一启动单片机就死机」问题。

### 2. 【最要紧】确保上电瞬间泵不会自己抽一下

ESP32 复位的那几百毫秒里，GPIO 处于**高阻输入**状态，继电器模块的 IN 引脚等于**悬空**。

* 如果模块是高电平触发：IN 悬空有可能被内部电路拉高 → **上电泵就转**。
* 如果是低电平触发：IN 悬空一般被拉高 → 不转，相对安全。

固件里已经做了防护（`PumpController::begin()` 里**先写输出电平、再切成 OUTPUT**），
但那只覆盖 `begin()` 之后的时刻，**从复位到 `begin()` 之间还有几百毫秒是固件管不到的**。

**做法**：在继电器模块的 IN 引脚和 GND 之间焊一只 **10kΩ 下拉电阻**
（低电平触发的模块则改成 IN 到 5V 的 10kΩ 上拉）。

**验收方法**：把泵接上但**不给水**，反复按 ESP32 的 RST 键 20 次，
每次只上电 2 秒就断电，看泵有没有啪的一下。有 → 电阻没接对。

### 3. 【最要紧】泵的干扰必须隔离，否则 ESP32 会随机复位

泵启停时 12V 母线会塌陷 + 叠加尖峰（电机启动电流是额定值的 3~5 倍，
0.45A × 4 ≈ **2A 的瞬间冲击**）。措施从便宜到彻底：

1. **泵的两根线拧成麻花**（双绞），并且**不要和信号线、传感器线捆在一起走**。
   传感器线（DS18B20 单总线对时序敏感）和泵电源线并行走线，是读数乱跳的头号元凶。
2. 泵接线端子处并 **100nF 陶瓷电容 + 100uF 电解电容**。
3. DC-DC 模块的 12V 输入处并 **470uF~1000uF 电解 + 100nF 陶瓷**。
4. **给 ESP32 单独用一路 DC-DC**（你有 3 个模块，别省）。
   泵和继电器模块走一路，ESP32 + 探头走另一路，只在电池负极处单点共地。

**验收方法**：固件里用 `mon 3` 和 `moff 3` 把最短启停改成 3 秒，
然后 `pump on` 让它自动跑 30 分钟（约 300 次启停）。
同时串口开 `log on` 抓日志，看有没有丢字符、时间戳跳变、或者板子重启（会重新打印启动横幅）。

### 4. 5 个继电器模块不要从 ESP32 板子取 5V

常见 5V 继电器模块每只吸合时约 **85mA**（线圈 70mA + 光耦 15mA）。
5 只同时吸合 ≈ **425mA**，已经接近很多 DC-DC 模块的实际余量和开发板 USB 口的能力。

* **直接从 DC-DC 的 5V 输出取电**，导线 >= 22AWG。
* 在继电器模块附近放一只 **100uF** 电解，吸收线圈吸合的瞬时电流。
* ESP32 开发板自己的 5V 脚（VIN）只供板子本身。

你的项目实际只用 1 个继电器，所以现在是 85mA，问题不大。
但既然固件里 `aux` 命令可以单独测剩下的 4 路，将来加 TEC / 风扇时就要按 425mA 规划。

### 5. 锂电池保护：欠压 + 保险丝，一个都不能少

* **保险丝**：电池正极出口串一只 **5A 快熔**，位置在**分流给继电器和 DC-DC 之前**。
  锂电短路电流能到几十安，不加保险丝就是点焊机。
* **欠压保护**：3S 锂电放到 9.0V 以下就永久损伤。绝大多数 DC-DC 降压模块**没有欠压关断**，
  会一直抽到 6V 以下。必须加 **3S BMS**，或者一只低压断电模块。
* **3 个电池组不要直接并联**。容量 / 内阻 / 老化程度不一致时会产生环流，
  轻则自放电，重则热失控。**一次用一个，用完换**。要并联就得加理想二极管均流板。

另外注意：12.6V 是 3S 的满电电压，放电到 9V 时泵的转速会明显下降
（有刷电机转速大致正比于电压），出水量大概掉到 75%。这对控温没影响（固件按温度闭环），
但要知道「电池快没电时降温会变慢」。

### 6. 湿区防护

12V 属于安全电压（< 36V），湿手碰到不会触电，但**水 + 锂电池在同一个背包里**是真风险。

* 电池放在**独立的防水盒**里，和水箱之间加一块**隔板**；
* 所有压接端子套热缩管，接头处打硅胶；
* ESP32 和 DC-DC 放进防水盒，盒底垫高 5mm，盒底打一个**朝下的**排水小孔；
* 充电时**绝对不要**背着或者靠近水路 —— 12.6V/2A 充电器进水是唯一可能真正出事的场景。

固件里留了一个**可选的漏水检测**（`include/config.h` 里 `ENABLE_LEAK_SENSOR`）：
在背包底部铺两根相距 2~3mm 的裸铜线接 GPIO18，遇水导通 → 立即停泵 + 蜂鸣器报警。
默认关闭（没接线时引脚悬空会误报），接好线再改成 `1`。

---

## 三、ESP32-S3 引脚分配（固件里已按这个写死）

| 功能 | GPIO | 备注 |
|---|---|---|
| DS18B20 单总线（5 探头并联） | **4** | 4.7kΩ 上拉到 **3V3**（不是 5V！） |
| 继电器 1 → 水泵 | **5** | 主输出 |
| 继电器 2 / 3 / 4 / 5 → 备用 | 6 / 7 / 15 / 16 | 用 `aux 1` ~ `aux 4` 单独开合 |
| 有源蜂鸣器（可选） | 17 | 没接也能跑 |
| 漏水检测（可选） | 18 | 默认关闭 |
| 板载状态灯 | 48 | DevKitC-1 v1.0 是 WS2812 彩灯 |

**这些脚绝对不要用**：

| GPIO | 原因 |
|---|---|
| 0 / 45 / 46 | strapping 脚，上电电平决定启动模式，接负载会导致烧录失败或启动异常 |
| 19 / 20 | ESP32-S3 原生 USB D- / D+ |
| 26 ~ 32 | 内部 SPI flash |
| 33 ~ 37 | **OPI PSRAM**（N16R8 模组，占用了就丢 8MB PSRAM） |
| 43 / 44 | UART0，接板载 CH343 串口桥（就是你电脑上的 COM 口） |

> 4.7kΩ 上拉一定要接 **3V3**。接到 5V 会经过上拉电阻倒灌进 GPIO，
> ESP32-S3 的 IO 不是 5V 耐受的，轻则读数乱跳重则烧脚。

---

## 四、继电器模块触发电平怎么测（10 分钟的事）

「丢石头」这类模块触发电平是可跳线的，**不同批次可能不一样**，别猜，实测：

1. 只给模块接 5V 和 GND，**不接泵**，用万用表蜂鸣档测 COM-NO 通断。
2. IN 引脚**悬空**：听有没有咔哒 → 记录（这就是上电瞬间的状态）。
3. IN 接 **5V**：听有没有咔哒。
4. IN 接 **GND**：听有没有咔哒。
5. 把 IN 接到 ESP32 的 GPIO，用 `aux 1 on` 和 `aux 1 off` 再各测一次 ——
   确认 **3.3V 的高电平也够驱动**。绝大多数模块可以，因为光耦 LED 串了 1k 电阻，
   3.3V 时电流约 (3.3 - 1.2) / 1000 ≈ 2.1mA，处在可用区间边缘，**一定要实测**。

据此设置 `include/config.h`：

```c
#define RELAY_ACTIVE_HIGH  1   // 高电平触发写 1，低电平触发写 0
```

**上电默认状态必须让泵停**，这是硬性安全要求。

---

## 五、完整接线图

```
                    ┌──────────────────────────┐
   12V 锂电组 ──┬───┤ 5A 快熔保险丝            │
   (3S, 带BMS)  │   └──────────────────────────┘
                │
                ├─────────────┬───────────────────────────┐
                │             │                           │
                │      ┌──────▼───────┐            ┌──────▼───────┐
                │      │ DC-DC 1      │            │ DC-DC 2      │
                │      │ 12V -> 5V/2A │            │ 12V -> 5V/2A │
                │      └──────┬───────┘            └──────┬───────┘
                │             │ 5V (>=22AWG)              │ 5V
                │      ┌──────▼───────┐            ┌──────▼───────┐
                │      │ 继电器模块   │            │ ESP32-S3     │
                │      │ VCC GND  IN  │            │ 5V  GND      │
                │      └──┬───┬────┬──┘            └──┬────┬──────┘
                │         │   │    │                  │    │
                │         │   │    └──── GPIO5 ───────┘    │
                │         │   └───────── GND ──────────────┤
                │         │                               │
                │      COM│  NO                           │
                │         │   │                           │
                │         │   └──────────►┌───────────┐    │
                ├─────────┘               │  365 泵    │   │
                │                         │  M  有刷   │   │
                └─────────────────────────┤            │   │
                       泵负极 ────────────┴───────────┘   │
                                                          │
                              ┌───────────────────────────┘
                              │
                    ┌─────────▼──────────┐
                    │  DS18B20 x5 并联    │
                    │  VDD  DQ  GND       │
                    │       │             │
                    │      4.7kΩ -> 3V3   │
                    │       └── GPIO4     │
                    └─────────────────────┘

   注意：泵两端必须反向并联续流二极管（阴极接 +12V）
   注意：泵的两根线拧成麻花，远离 DS18B20 的单总线
   注意：所有 GND 必须共地 —— 电池- / DC-DC / 继电器 / ESP32
```

---

## 六、上电量清单（跳过必炸，别跳）

- [ ] 电池正极出口有 5A 保险丝
- [ ] 泵两端有续流二极管，**方向没接反**
- [ ] 继电器 IN 有 10kΩ 上拉 / 下拉
- [ ] 继电器模块 VCC 来自 DC-DC，不是 ESP32 的 5V 脚
- [ ] DS18B20 上拉电阻接的是 **3V3** 不是 5V
- [ ] 所有 GND 共地
- [ ] 泵电源线与传感器线分开走线
- [ ] 电池和水箱物理隔开，充电时人不在旁边

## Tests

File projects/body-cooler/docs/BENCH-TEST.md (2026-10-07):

# 台架测试（继电器 + 水泵 + 电池）

## 事故记录（2026-10，已烧毁 1 台泵 + 1 块电源板）

| 项 | 当时的状态 | 后果 |
|---|---|---|
| 泵供电 | **从降压板的 12V 输出取电**（应该直接从电池取） | 降压板烧毁 |
| 保险丝 | **没装**（还没到货） | 没有任何过流保护 |
| 续流二极管 | **没装** | 电机反峰倒灌回降压板 |
| 结果 | 降压板先崩 → 泵欠压堵转 → 电流暴涨 | **泵 + 板子一起烧，冒烟** |

**结论：泵的电流路径上只能有「保险丝 + 继电器触点」两样东西。**

---

## 故障记录：接触器不吸合 / 探头扔进 50°C 热水也不开泵（2026-10-06，固件已修复）

**现象**

```
scan     -> idx 0  28CB4CAF11250680  UNASSIGNED  34.6     <- 角色丢了
状态灯    -> 红色快闪（FAULT）
水泵      -> 从不启动，继电器永不吸合
```

**根因：NVS 键名超过 15 字符，角色映射静默写入失败**

原代码把角色存成 `role_<16位ROM>` 的键名 = 3 + 16 = **21 字符**，
而 ESP-IDF 的 NVS 键名上限是 **15 字符**。`putUChar()` 直接返回失败，
但代码没检查返回值 → 每次断电/重启后角色都是空的。

于是启动时：

```
探头没有角色 -> skinAvg() 返回 NaN, water_out 也是 NaN
             -> updateSafetyLatch(): !haveSkin && !haveWOut -> enter = true
             -> m_safetyLatched = true -> 状态机进入 ST_FAULT
             -> 继电器被强制断开，无论水温多高都不吸合
```

所以「探头放 50°C 水里也不开泵」不是因为温度不够，是**联锁把泵锁死了**——
固件根本不知道哪个探头是体表探头。

**修复（3 处）**

| 文件 | 改动 |
|---|---|
| `src/tempsensor.cpp` | 短键名：`r<i>` 存「序号→ROM」，`m<i>` 存「序号→角色」，都 ≤ 3 字符 |
| `src/tempsensor.cpp` | `scan()` 重扫时按 ROM 把角色贴回去，重排序号不会串角色 |
| `src/console.cpp` | `scan` 不再调用 `loadRoles()`（原来它先清空内存角色，会抹掉刚 map 好的）；`map` 立即落盘 |

**另外新增：`status` 会直接告诉你为什么泵不开**

```
state   : REST      pump=OFF  force=auto enabled=yes mode=HYSTERESIS
reason  : 等最短停机结束：还差 23 秒        <- 新增行，一句话解释
```

常见 reason：

| reason | 含义 | 怎么解决 |
|---|---|---|
| `控温总开关关闭（enable on 打开）` | `enable off` 了 | 发 `enable on` |
| `等最短停机结束：还差 N 秒` | 上电后 30 秒内的正常等待 | 等，或 `pump on` 强制 |
| `体表 xxC < 开泵阈值 yyC` | 温度不够，本来就不该开 | 正常 |
| `安全联锁已锁：没有绑角色：体表/水温探头都没 map` | 角色丢了 | `scan` → `map skin_chest 0`（会自动存） |
| `安全联锁已锁：体表温度低于下限（过冷保护）` | 低于 30°C | 检查设定或 `clear` |

**实测验证（UART/USB 串口日志）**

```
map skin_chest 0   ->  OK: 28CB4CAF11250680 -> SKIN_CHEST    (已写入 NVS)
reboot             ->  scan 仍然显示 SKIN_CHEST      <- 角色这次活过了重启
enable on          ->  reason: 等最短停机结束：还差 23 秒
等待 30 秒          ->  state: PUMPING  pump=ON      <- 继电器自动吸合
```

**踩坑提醒：上电后 30 秒内泵不会启动**

`minOff = 30s` 是保护继电器触点和泵阀片的物理下限，上电时也照样生效。
所以「刚插上电，探头是热的，泵却不动」是**正常现象**，看 `reason` 行确认。
台架想立刻动泵就发 `pump on`（手动强制，绕过所有判断）。

---

## ★ 上电前 10 条检查（漏一条就可能再烧一次）

```
□ 1. 保险丝装了吗？       电池正极 → 保险丝 → 之后所有东西
                          （保险丝必须在分流之前，不能只保护某一路）

□ 2. 泵的电流路径对吗？   电池+ → 保险丝 → 继电器 COM → NO → 泵+ → 泵− → 电池−
                          ★ 中间不能有降压板、不能有信号地

□ 3. 续流二极管装了吗？   反向并联在泵两端，【阴极(有环端)朝泵+】
                          紧靠泵的接线端子

□ 4. 用的 NO 还是 NC？   必须 COM + NO。用 NC 逻辑反过来，泵会一直转

□ 5. 继电器 IN 的 10k 装对方向了吗？
    低电平触发模块(L) -> IN 用 10k 上拉到 VCC(5V)
    高电平触发模块(H) -> IN 用 10k 下拉到 GND      ★ 接反了复位期间会误吸合
    ★ 不确定就先不装，用串口 `relay test` 实测极性，再补电阻

□ 6. 泵放水里了吗？       干转几分钟阀片就废

□ 7. 先量通断：保险丝后 对 GND —— 不能导通（导通就是短路）

□ 8. 先量电流：万用表串在泵回路里，空载 ≤500mA，启动瞬间 ≤2A
                          ★ 电流不对就别接 ESP32

□ 9. 5V 从哪来？         ESP32 和继电器模块的 5V 从降压板来
                          ★ 泵绝不从降压板取电

□ 10. 人在旁边吗？        手放在总闸/电池接头上，闻到糊味立刻断
```

---

> 当前状态：你手上有 **继电器模块、365 水泵、12V 锂电池、ESP32-S3**。
> 温度探头还没接，所以先测**电机启停这一条链路**。
> 固件已经改成 **30 秒开泵 / 30 秒停泵**（台架测试模式，不看探头）。

---

# 一、接线表（现在这个口接那个口）

## 1.1 认识你的元件上的丝印

| 元件 | 上面印的字 |
|---|---|
| **ESP32-S3 开发板** | 两排引脚，每根旁边印着编号：`3V3` `3V3` `RST` `4` `5` `6` `7` … `5V` `GND`（**左排 J1，22 脚**）；`GND` `TX` `RX` `1` `2` `42` … `GND` `GND`（**右排 J3，22 脚**） |
| **继电器模块** | 控制侧 3 针：`VCC` `GND` `IN`；触点侧 3 位：`COM` `NO` `NC` |
| **DC-DC 降压模块** | `IN+` `IN-` `OUT+` `OUT-`（有的直接印 `+` `-`） |
| **365 水泵** | 两根引线：**红=正**，**黑=负**（没颜色就按外壳标记） |
| **锂电池组** | 出线：**红=正**，**黑=负** |
| **1N5822 二极管** | **一端有银灰色环** = 阴极 |

## 1.2 接线表（共 18 根线）

### 主回路：电池 → 保险丝 → 开关 → 继电器 → 水泵

| # | 从 | 到 | 线色 |
|---|---|---|---|
| 1 | 电池 **正极（红）** | 保险丝座 任意一端 | 红 |
| 2 | 保险丝座 另一端 | **汇流点 A** | 红 |
| 3 | **汇流点 A** | 肩带开关 任意一脚 | 红 |
| 4 | 肩带开关 另一脚 | 继电器 **COM** | 红 |
| 5 | 继电器 **NO** | 水泵 **正极（红）** | 红 |
| 6 | 水泵 **负极（黑）** | **汇流点 B** | 黑 |
| 7 | **汇流点 B** | 电池 **负极（黑）** | 黑 |

### 控制回路：电池 → DC-DC → 5V → ESP32 和继电器

| # | 从 | 到 | 线色 |
|---|---|---|---|
| 8 | **汇流点 A** | DC-DC **IN+** | 红 |
| 9 | **汇流点 B** | DC-DC **IN-** | 黑 |
| 10 | DC-DC **OUT+（5V）** | ESP32 **`5V` 脚**（J1 第 21 脚） | 蓝 |
| 11 | DC-DC **OUT-** | ESP32 **`GND` 脚**（J1 第 22 脚，或 J3 第 1/21/22 脚） | 黑 |
| 12 | DC-DC **OUT+（5V）** | 继电器 **VCC** | 蓝 |
| 13 | **汇流点 B** | 继电器 **GND** | 黑 |

### 信号与保护

| # | 从 | 到 | 线色 |
|---|---|---|---|
| 14 | ESP32 **`5` 脚**（J1 第 5 脚 = GPIO5） | 继电器 **IN** | 绿 |
| 15 | 继电器 **IN** | 10kΩ 电阻 一端 | — |
| 16 | 10kΩ 电阻 另一端 | 继电器 **GND** | — |
| 17 | 水泵 **正极** | 1N5822 **阴极（有环端）** | 蓝 |
| 18 | 水泵 **负极** | 1N5822 **阳极（无环端）** | 蓝 |

## 1.3 两个汇流点（压单个端子的地方）

```
汇流点 A  ← 3 根线：保险丝出、肩带开关进、DC-DC IN+
汇流点 B  ← 4 根线：水泵负极、电池负极、DC-DC IN-、继电器 GND
             （一个端子压不下 4 根就分两个端子，再并起来）
```

## 1.4 接线图

```
                    ┌──── 汇流点 A ────────────────────────┐
                    │           │                          │
   [电池 +]──[5A保险丝]──[肩带开关]──[继电器 COM]        [DC-DC IN+]
                                        │                     │
                                   (继电器触点)           [DC-DC]
                                        │                     │
   [电池 -]────────────[继电器 NO]  └──── 汇流点 B ────[DC-DC IN-]
       │                     │                │
       │              [水泵 正极]        [继电器 GND]
       └──────────────[水泵 负极]──┘
                            
   续流二极管：并联在水泵两端，阴极(有环端)朝水泵正极

   ESP32  ── 5V脚 ── DC-DC OUT+        ESP32 ── 5脚(GPIO5) ── 继电器 IN
          └─ GND脚 ── DC-DC OUT-       ESP32 ── GND脚 ────── 继电器 GND
```

---

# 一点五、触发电平接反了会怎样（★ 现场最容易踩的坑）

5V 光耦继电器模块有 **高电平触发(H)** 和 **低电平触发(L)** 两种，外形几乎一样，
有些板上还有跳线帽能切换。选错了**症状是「反着来」**：

| 固件里看到的 | 实际继电器 | 你观察到什么 |
|---|---|---|
| `state: PUMPING pump=ON` | **不吸合** | 该转的时候不转，怎么加热水都不开泵 |
| `state: FAULT pump=OFF` | **吸合** | 「泵没有关停，一直在转」，`enable off` 都停不下来 |
| `state: STANDBY pump=OFF` | 吸合 | 一上电泵就一直转，只有拔电池才停 |

**出现「反着来」先怀疑两件事**：

1. **触发电平选错**（下面这套流程按这个查）；
2. **ESP32 和继电器模块没有共地** —— 这种情况下 GPIO 的高/低对模块来说毫无意义，
   IN 相对模块 GND 的电平是漂的，表现会和「极性反了」一模一样。
   ★ 实测：`pump on` 时用万用表量 **IN 对模块自己的 GND**，不是对 ESP32 的 GND。

> 本项目实测：**IN 短接 GND 就吸合 -> 低电平触发(L)**，固件用 `RELAY_ACTIVE_HIGH 0`。

### ★ 第三种情况：极性对、线也对，但继电器就是放不掉

**实测记录（本项目真实踩到）**

```
把 GPIO5 直接短接到 GND        -> 泵转          (接线/极性/模块 全部正常)
固件输出 LOW  (0V)             -> 泵转          ✓
固件输出 HIGH (3.3V)           -> 泵【仍然】转   ← 问题在这
ESP32 复位(引脚高阻)            -> 泵停          ← 关键线索！
```

**原因：3.3V 不是这个模块的"高"。**

5V 光耦继电器模块的输入是：

```
模块 VCC(5V) ──[限流电阻]── 光耦 LED ──► IN 引脚
```

LED 的阴极接在 IN 上。IN 停在 **3.3V** 时，LED 上还剩 `5 - 3.3 - Vf(约1.2V) ≈ 0.5V` 的压差，
仍有微弱电流流过 —— 对灵敏的光耦来说**足够把继电器维持住**。
只有把 IN 真正拉到 **5V**（或让它悬空到没有电流回路），LED 才彻底截止。

* ESP32 推不出 5V -> 推挽输出解决不了。
* **引脚变高阻时 LED 没有回路 -> 彻底截止** -> 这就是「ESP32 一复位泵就停」的原因。

**解决：开漏驱动（固件已支持，不用改硬件电路）**

```
relay od      # 切到开漏：吸合 = 引脚推低 0V；释放 = 引脚变高阻
relay pp      # 切回推挽（默认）
```

配一只 **10k 电阻：模块 IN ──[10k]── 模块 VCC(5V)**（推荐但不是必须，
作用是让高阻状态被明确拉到 5V，抗电机干扰）。

切到 `relay od` 后 `status` 会这样显示：

```
relay   : IN实测=HIGH  指令=高阻(靠10k上拉)  驱动=开漏  极性=低电平触发  线圈=释放(泵停)
```

### 还有一个要查的：模块 VCC 到底几伏

万用表量 **模块 VCC 对 模块 GND**：

| 读数 | 说明 |
|---|---|
| 5.0V 左右 | 正常，用 `relay od` 即可 |
| 12V | **接错了** —— 模块是 5V 的，被接到 12V 上了，继电器会发热、寿命大减 |
| 3.3V | 接到 ESP32 的 3V3 上了，线圈可能吸不牢 |
| 0V | VCC 没接 |

## 怎么确认 / 怎么改（不用重新编译）

```
relay           # 看当前极性和 IN 引脚实测电平
relay test      # ★每 3 秒把 IN 翻一次，共 6 次 —— 用耳朵听
                 #  记下「哪一次咔哒」：
                 #    IN=HIGH 时咔哒  ->  relay high
                 #    IN=LOW  时咔哒  ->  relay low
relay high      # 改成高电平触发，立即保存到 NVS
relay low       # 改成低电平触发，立即保存到 NVS
```

改完极性后 `status` 会这样显示，可以直接对着看：

```
relay   : IN=LOW(实测)  极性=高电平触发  线圈=释放(泵停)
```

## 如果反了但一时不想改固件

低电平触发模块的输入通常是 `VCC ──[限流电阻]── 光耦LED ── IN`，
所以 **IN 悬空 = 没电流 = 释放**；高电平触发正好相反。
10k 电阻的方向必须跟着极性走，接反等于给模块加了反向偏置。

## 缺电阻会怎样

低电平触发模块的输入通常是：

```
模块 VCC(5V) ──[内部限流电阻]── 光耦 LED ── IN 引脚
```

所以 **IN 悬空 = 没有电流 = 继电器释放** —— 浮空本身是安全的（这点和高电平触发**相反**）。
缺上拉电阻的风险不在启动瞬间，而在于：

| 风险 | 表现 |
|---|---|
| 跳线当天线接收电机干扰 | 泵启停时继电器偶尔**无规律地啪一下** |
| ESP32 输出高只有 3.3V（模块 VCC 是 5V） | 压差只有 1.7V，光耦 LED 电流偏小，**极端情况下继电器释放不干脆** |

代码里已经做了能做的：`begin()` **先打开内部上拉（约 45k）再切输出**，
让 IN 在没人管时尽量保持高。但内部上拉太弱，挡不住强干扰。

## 没有电阻时怎么办

1. **先直接试**，但一定要用万用表确认：
   - 串口发 `pump off`（或等它进入停泵阶段）
   - 万用表**通断档**量继电器 **COM 和 NO** —— 应该是**断开（不通）**
   - 再发 `pump on`，应该变**导通**
   - 若 off 状态量出来是通的、或几百欧阻值 -> **继电器没完全释放** -> 必须加电阻
2. **把 IN 的跳线尽量剪短**，并**远离水泵电源线**（别平行捆一起）
3. **电阻到了立刻补上**：一端插 IN，另一端插模块 VCC(5V)
4. 上电时**盯着继电器听**：若上电瞬间啪一下再释放，说明浮空窗口有误动作

---

# 二、上电前必查（3 分钟，能省一次烧板子）

1. **万用表通断档**量「汇流点 A」和「汇流点 B」之间 —— **不能导通**。导通就是短路，立刻查线。
2. 确认继电器 **COM 和 NO** 用对了（**不是 NC**）。用 NC 的话逻辑反过来，泵会一直转。
3. 确认 **续流二极管方向**：有银环的一端接**水泵正极**。接反 = 直接把 12V 短路，会烧保险丝。
4. 确认 **ESP32 的 5V 脚**接的是 DC-DC 输出，**不是 3V3 脚**。
5. 确认**水泵正极接的是继电器 NO**，不是直接接电池正极（否则泵会一直转，不受控）。

---

# 三、上电顺序

```
① 先只接电池，不插 ESP32，不接泵
   万用表量 DC-DC 输出：应该是稳定的 5.0V

② 接 ESP32（USB 先别插），看板子灯亮、串口有输出
   此时继电器应该不动作（10k 下拉在起作用）

③ 接继电器控制线（VCC / GND / IN）
   固件已经在跑台架模式 → 应该立刻开始 30 秒响一下 / 停 30 秒
   只听咔哒声，先不接泵

④ 最后接泵
   ⚠ 泵必须有水可抽 —— 放一盆水让它循环，绝对不要长时间干转
```

---

# 四、固件现在是什么行为

烧进去的固件**默认就是台架测试模式**，上电后：

```
每 30 秒开泵 ── 每 30 秒停泵 ── 循环
```

**它完全绕过安全联锁** —— 不管有没有温度探头、水温多少、有没有缺水，都按固定节拍开关。

## 串口命令

| 命令 | 作用 |
|---|---|
| `status` | 看当前状态（`state` 会在 `PUMPING` / `REST` 之间跳） |
| `showcfg` | 看台架参数 |
| `bench 30` | 改节拍：30 秒开 / 30 秒停（也可以 `bench 5` 快速测试） |
| `enable off` | **停**（立刻停泵，不再自动开） |
| `enable on` | 恢复自动节拍 |
| `pump off` | 手动强制停 |
| `pump on` | 手动强制开（会一直开，小心） |
| `pump auto` | 交回自动 |
| `mode 0` | **退出台架模式**，回到正常控温（需要温度探头才能工作） |
| `mode 2` | 回到台架模式 |
| `savecfg` | 把当前设置存到 NVS |

## 状态灯

| 灯 | 含义 |
|---|---|
| 青色快闪（2Hz） | **泵在转**（继电器吸合） |
| 黄色双闪 | 泵停，在等下一个 30 秒 |

---

# 五、这次测试要验证什么

| 项 | 通过标准 |
|---|---|
| 继电器能吸合/释放 | 每 30 秒听到一声清脆的咔哒，不是拖泥带水的嗡嗡声 |
| 时序正确 | 用秒表掐：开 30 秒 ±1 秒，停 30 秒 ±1 秒 |
| 泵确实转 | 接水后能听到水流声 / 看到水在管里动 |
| **ESP32 不重启** | 连续跑 20 分钟，串口不出现新的启动横幅 |
| 串口不丢字符 | `log on` 期间输出连续，没有乱码 |
| 电池电压不塌 | 泵启动瞬间 DC-DC 输出 5V 不抖到 4.5V 以下 |

## 重点看第 4 项

泵启动瞬间电流是额定的 3~5 倍（0.45A × 4 ≈ **2A**），会在 12V 母线上砸出一个坑，
同时电刷打火产生高频尖峰。**如果 ESP32 会因此复位，说明续流二极管和滤波电容没做到位。**

测试方法：`log on`，让它跑 20 分钟（约 20 个循环），盯着串口。
如果出现新的 `===== body-cooler =====` 启动横幅 → **ESP32 复位了** → 回去查 P0-1（续流二极管）和 P0-3（滤波电容）。

---

# 六、出问题怎么办

| 现象 | 原因 | 处理 |
|---|---|---|
| **反着来**：固件说 ON 却不吸合 / 说 OFF 反而一直转 | ① 触发电平选反 ② ESP32 与模块**没共地** | 先量 IN 对**模块 GND**；再 `relay test` 听咔哒声定位；极性用 `relay high`/`relay low` 现场切 |
| 继电器一直吸合不释放 | 用了 NC 触点 | 改接 COM + NO |
| 继电器一直不动作（极性已确认正确） | IN 没接对 / 模块 VCC 没 5V | 万用表量 IN 对 GND：`pump on` 时应该等于吸合电平 |
| 上电瞬间泵抽一下 | IN 悬空被拉高 | 加 10k 下拉（接线表第 15/16 根） |
| 泵转了但没水 | 没灌引水 / 进水管漏气 | 从回水管倒水进罐，把泵泡一下 |
| ESP32 反复重启 | 电机干扰 | 查续流二极管方向、加分路 DC-DC、加滤波电容 |
| 串口乱码 | 波特率不对 | 必须是 115200 |
| 泵转速明显变慢 | 电池电压低了 | 量电池，低于 10.5V 该充电了 |

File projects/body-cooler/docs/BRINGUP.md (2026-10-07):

# 桌面测试流程（分 7 步，别跳步）

原则：**从最便宜、最不容易炸的东西开始。** 每一步都确认通过了再进下一步。
每一步只引入一个新变量，出问题时才能定位。

---

## 第 0 步：不接任何外设，只上 ESP32

```powershell
# 在工作区根目录执行
.\scripts\pio.ps1 run -d .\projects\body-cooler -t upload --upload-port COM5
.\.venv\Scripts\python.exe .\scripts\serial_capture.py --port COM5 --seconds 8 --reset
```

**期望看到**：

```
=============================================================
  body-cooler  --  ESP32-S3 全身降温器固件
  build ...
=============================================================
chip       : ESP32-S3 ...
flash      : 16 MB    psram: 8386279 bytes
--- pin map ---
  DS18B20 bus : GPIO4  (4.7k 上拉到 3V3)
  relay pump  : GPIO5 (高电平 触发)
...
DS18B20     : 总线发现 0 个探头
  !! 没找到温度探头 —— 自动控温会被安全联锁锁住（state=FAULT）。
  !! 台架测试可用: pump on / pump auto 手动驱动继电器。
```

**通过标准**：`flash` 是 16 MB，`psram` 是约 8 MB，没有重启循环。

> PSRAM 显示 0 → `platformio.ini` 里的 `-DBOARD_HAS_PSRAM` 丢了，见技能文档坑 4。

输入 `help` 和 `status` 确认串口命令行有响应。

---

## 第 1 步：接 1 个 DS18B20（带 4.7k 上拉）

接线：`VDD -> 3V3`、`GND -> GND`、`DQ -> GPIO4`，`4.7k` 电阻跨接在 **DQ 和 3V3** 之间。

```
scan
```

**期望**：列出 1 行 `28FF........` 的 ROM。

**温度校准**：把探头丢进**冰水混合物**（冰 + 少量水，搅匀），等 2 分钟，读数应该是 **0.0 正负 0.5 度**。
常温下应该接近室温。偏差超过 1 度 → 探头有问题，或者线太长 / 上拉电阻太大。

总线上一个探头都没有时的排查顺序：

1. 4.7k 上拉是不是接的 **3V3**（接 5V 会烧 GPIO）；
2. DQ 是不是真的接到了 GPIO4；
3. 探头三根线的颜色定义 —— **不同厂家不一样**！红的可能是 VDD 也可能是 DQ，
   用万用表量一下二极管压降确认；
4. 线太长（超过 5 米）→ 把上拉换成 2.2k。

---

## 第 2 步：接齐 5 个探头并分配角色

```
scan                          # 确认 5 个都在
map water_out   0             # 罐出水口（最冷点）
map water_ret   1             # 回水口（最热点）
map skin_chest  2             # 胸前体表
map skin_back   3             # 后背体表
map ambient     4             # 背包内环境
roles                         # 复查
save                          # 写进 NVS，掉电不丢
```

**角色分工的理由**：

| 角色 | 位置 | 作用 |
|---|---|---|
| `water_out` | 罐出水口 / 泵入口 | 系统最冷点，用于过冷保护（`wmin`） |
| `water_ret` | 回水进罐处 | 与出水口的温差 = 从身上带走的热量，用于估算制冷功率和判断冰袋是否失效 |
| `skin_chest` / `skin_back` | 贴身速干衣内侧 | 控温主反馈量（两个取平均） |
| `ambient` | 背包内 | 监控罐外壁结露风险 |

> 探头用**医用胶布 / 薄敷贴**固定在速干衣内侧，金属探头不要直接压在皮肤上，
> 长时间会形成压痕和局部冷点 —— 中间垫一层薄棉布。

---

## 第 3 步：只测继电器模块（不接泵！）

这一步是为了确定**触发电平**和**上电行为**，见 `docs/WIRING-REVIEW.md` 第四节。

```
aux 1 on
aux 1 off
```

听继电器有没有咔哒声，用万用表蜂鸣档量 COM-NO 通断。

**关键测试**：按住 RST 键反复复位 20 次，听继电器有没有在上电瞬间乱响。
有 → 必须在 IN 引脚上加 10k 上拉 / 下拉，然后回到第 3 步重测。

确认后设置 `include/config.h` 里的 `RELAY_ACTIVE_HIGH`，重新编译烧录。

---

## 第 4 步：接泵（先不接水），测电磁干扰

**泵绝对不能长时间空转。** 每次开 **不超过 3 秒**，间隔 15 秒以上。

```
pump on
# 等 3 秒
pump off
```

重复 20 次左右，同时开着 `log on` 看串口。

**通过标准**：

* 泵每次都正常启动 / 停止；
* 串口**不丢字符**、时间戳不跳变；
* ESP32 **不重启**（没有重新打印启动横幅）；
* 继电器吸合的声音干脆（不是拖泥带水的嗡嗡声）。

失败 → 按 `docs/WIRING-REVIEW.md` 问题 1 和问题 3 加二极管和电容。

---

## 第 5 步：加水，测密封和循环

按 `docs/SEALING-REVIEW.md` 第五节做：

1. **静态保压**：堵住进出口，纸巾垫底，静置 30 分钟看渗漏；
2. **动态循环**：装满水，`pump on` 连续跑 30 分钟，观察所有接头；
3. **倒置测试**：罐子倒过来放 5 分钟，模拟背包晃动。

注意听泵的声音 —— **明显的咕噜咕噜气泡声 = 进水口漏气**，检查卡箍和宝塔头。

顺便记下**实际流量**：用一个量杯接住出水口，跑 60 秒，量出多少毫升。
然后用 `flow <L/min>` 把实测值填进去，`savecfg` 保存。
（`flow` 只影响串口打印的估算制冷功率，不影响控温逻辑，但填准了很有参考价值。）

---

## 第 6 步：控温回路测试（不穿上身）

这一步用温度计和水杯来骗固件。

1. 把 `skin_chest` 和 `skin_back` 两个探头一起丢进 **35 度的温水**里；
2. `water_out` 探头丢进 **冰水**里（模拟罐里出来的冷水）；
3. `enable on`，开 `log on`。

**期望行为**：

* 体表读数 35 度 > 目标 33 度 + 回差一半 → **泵启动**；
* 把体表探头换到 **32 度的水**里 → 泵仍然继续跑（因为还没到最短运行时间 20 秒，
  而且回差下限是 32.5 度）；
* 换到 **28 度的水**里 → 会触发 `WARN_SKIN_LOW`，**泵立即停**（安全联锁打断最短运行时间），
  LED 变红闪，`state=FAULT`；
* 把体表探头放回 35 度水 → `clear` 之后恢复正常；
* 把 `water_out` 探头从冰水里拿出来放室温 → 超过 32 度时触发 `WARN_WATER_HIGH`。

**再测占空比模式**：

```
mode 1        # 时间比例（慢 PWM）
log on
```

把体表探头放在 34 度温水里，观察泵是不是按 3 分钟一个周期间歇运行，
`duty10m` 应该在 30% ~ 70% 之间随温度变化。

**验证「不能 PWM」这条约束是否被遵守**：
整个测试过程中，继电器**只应该整段开、整段关**，
任何情况下都不应该听到高频哒哒哒的声音。最短运行 20 秒 / 最短停机 30 秒保证了这一点。

---

## 第 7 步：上身测试（最后一步）

**前置条件：第 0 ~ 6 步全部通过。**

1. 先穿**紧身速干衣**打底，软管走在速干衣外面、外套里面；
2. 第一次只跑 **10 分钟**，全程有人陪着，随时能拔掉电源；
3. 观察：体表温度有没有降下来、有没有局部过冷 / 发麻 / 起疹子、
   冷凝水有没有渗到衣服上；
4. 逐步加长到 30 分钟、60 分钟。**单次不要超过 60 分钟。**

**手感比温度数字重要**：如果觉得某一段特别冷或者刺痛，立刻停，
那段管子要么加一层布垫，要么换个走向。

---

## 附：常用串口命令速查

| 命令 | 作用 |
|---|---|
| `status` | 打印一次完整状态（温度 / 状态机 / 报警 / 统计） |
| `scan` | 重新扫描总线并列出 ROM / 角色 / 温度 |
| `log on` | 每 2 秒自动打印一次状态；`rate 5000` 改成 5 秒 |
| `pump on` / `pump off` / `pump auto` | 手动强制 / 交回自动 |
| `enable on` / `enable off` | 控温总开关 |
| `clear` | 清除安全联锁（过冷 / 漏水故障后手动复位） |
| `aux 1 on` | 手动开 1 号备用继电器（1 ~ 4） |
| `target 33.0` | 改体表目标温度 |
| `band 1.0` | 改回差 |
| `wmin 10` | 改水温下限（建议实测后调到 10 ~ 12） |
| `mode 1` | 切到时间比例（慢 PWM）模式 |
| `savecfg` | 保存设定到 NVS |
| `save` | 保存探头角色映射到 NVS |

抓日志：

```powershell
.\.venv\Scripts\python.exe .\scripts\serial_capture.py --port COM5 --seconds 300
```

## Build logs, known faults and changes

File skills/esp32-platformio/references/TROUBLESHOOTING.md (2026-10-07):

# 故障排查

按「症状」查表，再到下面找详细解释。带 ★ 的是本项目实际踩过的坑。

## 速查表

| 症状 | 最可能原因 | 一句话修复 |
|---|---|---|
| ★ `requires an interactive terminal on stdin` | 用了 `pio device monitor` | 改用 `scripts/serial_capture.py` |
| ★ `'class EspClass' has no member named 'getCoreVersion'` | 该 API 在 arduino-esp32 2.x 不存在 | 用 `ESP_ARDUINO_VERSION_MAJOR` 宏 |
| ★ PSRAM 恒为 0，其它一切正常 | 只设了 `memory_type`，漏了 `-DBOARD_HAS_PSRAM` | 加 `-DBOARD_HAS_PSRAM` |
| ★ `PermissionError: [Errno 13] Permission denied ... tmpXXXX` | 沙箱里 `mkdtemp` 的 DACL 顶掉了能力 ACE | 装 `sitecustomize.py` 补丁 |
| ★ 下载卡在 `Downloading 0%` 几分钟不动 | 直连 registry 被限速到 ~17 kB/s | 配置 `.pio-proxy` |
| ★ `Got unexpected extra argument` | `-d` 写在了子命令前面 | 写成 `run -d <dir><` |
| ★ `A parameter cannot be found that matches parameter name 'e'` | 包装脚本声明了 `param()` | 包装脚本不要有 param 块 |
| `Looking for upload port...` 之后失败或选错口 | CH343 不匹配板定义的 hwids | 显式 `--upload-port COM5` |
| `Failed to connect to ESP32-S3: Timed out waiting for packet header` | 没进下载模式 / 口被占用 | 见下文「连不上」 |
| 串口输出乱码 | 波特率不对 | `monitor_speed` / `--baud` 对齐 115200 |
| 上电后反复重启 | memory_type 选错 / 分区表越界 | 见下文「bootloop」 |
| `Sketch too big` / 分区放不下 | app 分区太小 | 换 `default_16MB.csv` 或 `huge_app.csv` |
| `warning: "CORE_DEBUG_LEVEL" redefined` | 框架和自己都定义了 | 无害；或加 `build_unflags` |
| `This command is deprecated ... use 'pio pkg install'` | `platform install` 已弃用 | 或用 `pio pkg install -g -p espressif32` |
| ★ `File contains no section headers` | platformio.ini 存成了**带 BOM** 的 UTF-8 | 用无 BOM 的 UTF-8 重写 |

## ★ 连不上板子（Failed to connect / Timed out）

按顺序排查：

1. **口对不对**：`--upload-port COM5`。CH343 是 `VID_1A86 PID_55D3`，
   不是 Espressif 的 `303A`，板定义里的 hwids 匹配不到它。
2. **口被占用**：串口监视器、另一个 pio 进程、VSCode 串口插件都会占住口。被占用通常报
   `could not open port ... Access is denied`。
3. **没进下载模式**：ESP32-S3 靠 CH343 的 DTR/RTS 自动进下载模式。精简板若省掉了自动复位电路，
   就要手动：**按住 BOOT → 点一下 RST → 松开 BOOT**，再立刻重跑上传。
4. **供电/线材**：劣质线会让烧录中途掉线。换线，或插机箱后面的 USB 口。
5. **降速**：`upload_speed = 115200`（默认 921600）。

手动复位时序就是这两根线：

```python
ser.setDTR(False)
ser.setRTS(True)     # RTS -> EN 拉低 = 复位
time.sleep(0.12)
ser.setRTS(False)
```

## ★ bootloop / 一上电就重启

八成是 `memory_type` 选错。日志里会出现：

```
rst:0x3 (RTC_SW_SYS_RST),boot:0x8 (SPI_FAST_FLASH_BOOT)
invalid header: 0xffffffff
```

对照 `.platformio\packages\framework-arduinoespressif32\tools\sdk\esp32s3\` 下的目录名
（`qio_opi` / `qio_qspi` / `opi_opi` …）挑一个。
封装内 8 MB PSRAM 的 ESP32-S3 → `qio_opi`。

改完必须 `-t clean`：memory_type 会换掉 `sections.ld` 和静态库，
增量编译可能留下不一致的目标文件。

## ★ PSRAM 显示 0 / `psramFound()` 为 false

两个开关缺一不可，见 `references/PLATFORMIO_INI.md` 的「PSRAM 的两个开关」。确认顺序：

```powershell
# 1. 烧录日志里有没有 Embedded PSRAM 8MB -> 证明板子硬件确实有
.\scripts\pio.ps1 run -d .\projects\hello-s3 -t upload --upload-port COM5 | Select-String "PSRAM|Chip is"

# 2. ini 里三个字段都在
Select-String -Path .\projects\hello-s3\platformio.ini -Pattern "memory_type|BOARD_HAS_PSRAM|flash_size"
```

## ★ flash 容量不对（显示 8 MB 或 4 MB）

`esp_flash_get_size()` 返回的是运行时探测值，一般可信。如果显示 8 MB，要么板子真不是
16 MB，要么 `board_upload.flash_size` 没设对。两个字段都要对上：
`board_upload.flash_size = 16MB` 与 `board_build.partitions = default_16MB.csv`。

最硬的自检是 esptool 烧录日志：

```
Chip is ESP32-S3 (QFN56) (revision v0.2)
Features: WiFi, BLE, Embedded PSRAM 8MB (AP_3v3)
```

## ★ File contains no section headers（platformio.ini 带 BOM）

```
InvalidProjectConfError: Invalid 'platformio.ini' (project configuration file):
'File contains no section headers.
```

Windows PowerShell 5.1 的 `Set-Content -Encoding UTF8` 会写入 **UTF-8 BOM**（`EF BB BF`），
PlatformIO 的 ini 解析器看到开头是 BOM 而不是 `[`，就认定整份文件没有任何 section。文件内容看起来
完全正常，只有头三个字节不对 —— 用十六进制看一眼即可确认：

```powershell
$b = [System.IO.File]::ReadAllBytes('.\projects\my-app\platformio.ini')
($b[0..2] | ForEach-Object { $_.ToString('X2') }) -join ' '   # EF BB BF = 有 BOM，要修
```

修法：用无 BOM 的 UTF-8 重写（`Out-File -Encoding utf8NoBOM` 是 PowerShell 7+ 才有的，
5.1 上要用 .NET）：

```powershell
$text  = Get-Content '.\projects\my-app\platformio.ini' -Raw
$noBom = New-Object System.Text.UTF8Encoding($false)
[System.IO.File]::WriteAllText((Resolve-Path '.\projects\my-app\platformio.ini'), $text, $noBom)
```

`scripts/new_project.ps1` 已经用 `WriteAllText + UTF8Encoding($false)` 生成文件，
不会踩这个坑。本机 `pwsh` 实为 Windows PowerShell 5.1，所以这条要一直留意。

## ★ 沙箱环境：temp 目录 PermissionError

```
PermissionError: [Errno 13] Permission denied: 'D:\...\.tmp\tmpab12cd\x.txt'
```

这是 DSH 文件沙箱特有的：沙箱靠父目录上一条**可继承的能力 ACE** 授予写权限，而 CPython 的
`tempfile.mkdtemp()` 会按 mode `0o700` 向 Windows 请求一条**显式 DACL**，
把继承来的 ACE 顶掉了 —— 刚建好的目录自己都写不进去。pip / ensurepip 全靠私有临时目录暂存文件，
于是直接崩。

`scripts/dsh_sandbox_shim.py` 把 `os.mkdir` 的 mode 强制回默认值修好这件事，
`bootstrap.ps1` 会把它装成 venv 的 `sitecustomize.py`（每个进程自动加载）。
这一步**必须早于 ensurepip**，否则 pip 自己都装不上。

## ★ 下载慢 / 看起来卡住

直连 `dl.registry.platformio.org` 实测 ~17 kB/s，走本地代理 ~248 kB/s（14 倍）。
代理地址写在 `.pio-proxy`（一行，如 `http://127.0.0.1:7897`），
`pio.ps1` 先探测端口再决定用不用，端口不通自动回退直连。

另外：`Out-String` 这类管道会把输出全部缓冲住，看起来像"卡死"，其实在正常下载。
要看实时进度就别套 `Out-String`。

## ★ 包装脚本参数传不进去

```powershell
# 错：声明了 param 块 -> PowerShell 抢走 -e / -t 并报绑定失败
param([Parameter(ValueFromRemainingArguments=$true)][string[]]$PioArgs)
& $python -m platformio @PioArgs
```

正确做法是**不写 param 块**，直接用 `$args`：

```powershell
& $python -m platformio @args
```

实测：无 param 块时 `run -e x -t upload -v` 六个 token 原样进 `$args`。

## ★ 串口工具报 requires an interactive terminal

pio 的 monitor 在非 TTY 环境直接拒绝运行。用技能自带的：

```powershell
.\.venv\Scripts\python.exe .\scripts\serial_capture.py --port COM5 --seconds 10 --reset
.\.venv\Scripts\python.exe .\scripts\serial_capture.py --port COM5 --seconds 5 --expect "boot OK"
```

`--expect` 让它能当断言用：找到退出 0，没找到退出 1，完全无数据退出 3。

## API 版本坑（arduino-esp32 2.0.17）

| 想做的事 | 2.0.17 里的写法 |
|---|---|
| Arduino 内核版本 | `ESP_ARDUINO_VERSION_MAJOR/MINOR/PATCH`（**没有** `getCoreVersion()`） |
| 芯片型号 | `ESP.getChipModel()` |
| 芯片核数 | `ESP.getChipCores()` |
| 芯片修订号 | `ESP.getChipRevision()` — S3 + IDF 4.4 上恒为 0，**不可信**，以 esptool 日志为准 |
| PSRAM | `ESP.getPsramSize()` / `ESP.getFreePsram()` |
| flash 容量 | `esp_flash_get_size(NULL, &size)`（需 `#include <esp_flash.h><`） |
| MAC | `esp_read_mac(mac, ESP_MAC_WIFI_STA)`（需 `#include <esp_mac.h><`） |

## 万一还是不行

从干净状态重建（会重下 ~700 MB，确认代理可用）：

```powershell
Remove-Item -Recurse -Force .venv, .platformio
.\scripts\bootstrap.ps1
.\scripts\pio.ps1 run -d .\projects\hello-s3 -t upload --upload-port COM5
.\.venv\Scripts\python.exe .\scripts\serial_capture.py --port COM5 --seconds 8 --reset
```

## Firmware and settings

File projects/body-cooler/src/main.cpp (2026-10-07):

// =============================================================================
//  body-cooler  --  ESP32-S3 全身降温器主循环
//
//  任务分工（全部非阻塞）：
//    sensors.tick()   DS18B20 异步采样状态机（每 ~2s 一轮）
//    pump.tick()      控温状态机（每 500ms 一次判决）
//    console.tick()   串口命令解析
//    blinkTick()      状态灯
//    buzzerTick()     蜂鸣器报警
//
//  loop() 里没有任何 delay()，所以串口随时有响应，采样也不会互相打架。
// =============================================================================
#include <Arduino.h>
#include "config.h"
#include "tempsensor.h"
#include "controller.h"
#include "console.h"
#include "inputs.h"

// ---------------------------------------------------------------------------
//  备用继电器
// ---------------------------------------------------------------------------
static const int AUX_PINS[4] = {PIN_RELAY_AUX1, PIN_RELAY_AUX2, PIN_RELAY_AUX3, PIN_RELAY_AUX4};

void auxWrite(int idx, bool on) {
  if (idx < 0 || idx > 3) return;
  const bool level = RELAY_ACTIVE_HIGH ? on : !on;
  digitalWrite(AUX_PINS[idx], level ? HIGH : LOW);
}

// ---------------------------------------------------------------------------
//  状态灯
//  图案格式：{亮ms, 灭ms, 亮ms, 灭ms, ...} 循环播放
// ---------------------------------------------------------------------------
// 上电自检图案：绿色 3 短闪 = 正常上电；红色狂闪 = 检测到欠压复位(BROWNOUT)
static const uint16_t PAT_BOOT_OK[]  = {70, 130, 70, 130, 70, 1100};
static const uint16_t PAT_BOOT_BAD[] = {60, 60};
// 继电器状态变化瞬间：绿色常亮一小会儿
static const uint16_t PAT_EDGE[]     = {400, 400};

static uint32_t g_bootUntil = 0;
static bool     g_bootBad   = false;
static uint32_t g_edgeUntil = 0;
static bool     g_lastRelay = false;

static const uint16_t PAT_STANDBY[] = {20, 2980};
static const uint16_t PAT_MONITOR[] = {60, 940};
static const uint16_t PAT_REST[]    = {60, 200, 60, 680};
static const uint16_t PAT_PUMPING[] = {250, 250};
static const uint16_t PAT_FAULT[]   = {80, 120, 80, 120, 80, 840};

struct Blinker {
  const uint16_t* pat;
  uint8_t  n;
  uint8_t  i;
  uint32_t t;
  bool     level;
};

static Blinker  g_blink;
static uint8_t  g_r, g_g, g_b;

static void ledApply(bool on) {
#if LED_IS_WS2812
  if (on) neopixelWrite(PIN_STATUS_LED, g_r, g_g, g_b);
  else    neopixelWrite(PIN_STATUS_LED, 0, 0, 0);
#else
  digitalWrite(PIN_STATUS_LED, on ? HIGH : LOW);
#endif
}

// 强制切换图案（即使图案相同也重新开始）—— 用于继电器切换瞬间的绿闪
static void blinkForce(const uint16_t* p, uint8_t n, uint8_t r, uint8_t g, uint8_t b) {
  g_blink.pat = p; g_blink.n = n; g_blink.i = 0;
  g_blink.t = millis(); g_blink.level = true;
  g_r = r; g_g = g; g_b = b;
  ledApply(true);
}

static void blinkUse(const uint16_t* p, uint8_t n, uint8_t r, uint8_t g, uint8_t b) {
  if (g_blink.pat == p && g_blink.n == n) return;   // 同图案不重启，避免闪断
  g_blink.pat = p;
  g_blink.n = n;
  g_blink.i = 0;
  g_blink.t = millis();
  g_blink.level = true;
  g_r = r; g_g = g; g_b = b;
  ledApply(true);
}

static void blinkTick() {
  if (!g_blink.pat) return;
  uint32_t now = millis();
  if (now - g_blink.t >= g_blink.pat[g_blink.i]) {
    g_blink.t = now;
    g_blink.level = !g_blink.level;
    g_blink.i = (uint8_t)((g_blink.i + 1) % g_blink.n);
    ledApply(g_blink.level);
  }
}

static void ledUpdateForState() {
  // 1) 上电自检阶段：绿 3 闪 = 正常；红狂闪 = 上次是欠压复位（BROWNOUT）
  if (millis() < g_bootUntil) {
    if (g_bootBad) blinkUse(PAT_BOOT_BAD, sizeof(PAT_BOOT_BAD)/sizeof(PAT_BOOT_BAD[0]), 70, 0, 0);
    else           blinkUse(PAT_BOOT_OK,  sizeof(PAT_BOOT_OK) /sizeof(PAT_BOOT_OK [0]), 0, 70, 0);
    return;
  }
  // 2) 继电器刚切换：绿色常亮一下，方便和「听到的咔哒声」对齐
  if (millis() < g_edgeUntil) {
    blinkUse(PAT_EDGE, sizeof(PAT_EDGE)/sizeof(PAT_EDGE[0]), 0, 70, 0);
    return;
  }
  const uint32_t w = pump.warnings();
  if (pump.state() == ST_FAULT || (w & (WARN_SKIN_LOW | WARN_WATER_LOW | WARN_SENSOR_FAULT | WARN_NO_SENSOR))) {
    blinkUse(PAT_FAULT, sizeof(PAT_FAULT) / sizeof(PAT_FAULT[0]), 60, 0, 0);        // 红：故障
    return;
  }
  if (w & (WARN_SKIN_HIGH | WARN_WATER_HIGH | WARN_DRY_RUN | WARN_ICE_MELT)) {
    blinkUse(PAT_REST, sizeof(PAT_REST) / sizeof(PAT_REST[0]), 60, 30, 0);         // 橙：报警
    return;
  }
  switch (pump.state()) {
    case ST_PUMPING:
      blinkUse(PAT_PUMPING, sizeof(PAT_PUMPING) / sizeof(PAT_PUMPING[0]), 0, 40, 40);  // 青：泵转
      break;
    case ST_REST:
      blinkUse(PAT_REST, sizeof(PAT_REST) / sizeof(PAT_REST[0]), 40, 40, 0);           // 黄：等最短停机
      break;
    case ST_MONITOR:
      blinkUse(PAT_MONITOR, sizeof(PAT_MONITOR) / sizeof(PAT_MONITOR[0]), 0, 30, 0);   // 绿：待命
      break;
    case ST_STANDBY:
    default:
      blinkUse(PAT_STANDBY, sizeof(PAT_STANDBY) / sizeof(PAT_STANDBY[0]), 0, 0, 25);   // 蓝：待机
      break;
  }
}

// ---------------------------------------------------------------------------
//  蜂鸣器（可选硬件；没接也不影响）
// ---------------------------------------------------------------------------
static uint32_t g_buzzUntil = 0;
static uint32_t g_buzzNext  = 0;

static void buzzerTick() {
  const uint32_t now = millis();
  if (g_buzzUntil && now >= g_buzzUntil) {
    digitalWrite(PIN_BUZZER, LOW);
    g_buzzUntil = 0;
  }
  const uint32_t w = pump.warnings();
  const bool urgent = (pump.state() == ST_FAULT) ||
                      (w & (WARN_SKIN_HIGH | WARN_SKIN_LOW | WARN_WATER_LOW | WARN_WATER_HIGH | WARN_DRY_RUN));
  if (!urgent || g_buzzUntil != 0 || now < g_buzzNext) return;
  digitalWrite(PIN_BUZZER, HIGH);
  g_buzzUntil = now + 80;
  g_buzzNext  = now + 4000;
}

// ---------------------------------------------------------------------------
void setup() {
  Serial.begin(115200);
#if ARDUINO_USB_CDC_ON_BOOT
  // 走原生 USB 时，等主机打开串口再打印，否则启动横幅会丢
  { uint32_t t0 = millis(); while (!Serial && (millis() - t0 < 2500)) delay(10); }
#endif
  delay(300);

  // 先把所有输出脚置成「关」，再配置 LED / 蜂鸣器
  pinMode(PIN_BUZZER, OUTPUT);
  digitalWrite(PIN_BUZZER, LOW);

#if !LED_IS_WS2812
  digitalWrite(PIN_STATUS_LED, LOW);
  pinMode(PIN_STATUS_LED, OUTPUT);
  digitalWrite(PIN_STATUS_LED, LOW);
#endif
  ledApply(false);

  esp_reset_reason_t rr = esp_reset_reason();
  g_bootBad   = (rr == ESP_RST_BROWNOUT);
  g_bootUntil = millis() + 2600;
  const char* rrName =
      (rr == ESP_RST_POWERON)  ? "POWERON 正常上电" :
      (rr == ESP_RST_BROWNOUT) ? "BROWNOUT 掉电/欠压复位 <<< 电源有问题" :
      (rr == ESP_RST_PANIC)    ? "PANIC 程序崩溃" :
      (rr == ESP_RST_INT_WDT)  ? "INT_WDT 中断看门狗" :
      (rr == ESP_RST_TASK_WDT) ? "TASK_WDT 任务看门狗" :
      (rr == ESP_RST_WDT)      ? "WDT 看门狗" :
      (rr == ESP_RST_SW)       ? "SW 软件重启" :
      (rr == ESP_RST_DEEPSLEEP)? "DEEPSLEEP 唤醒" :
      (rr == ESP_RST_EXT)      ? "EXT 外部复位脚" : "其他";

  Serial.println();
  Serial.println(F("============================================================="));
  Serial.printf ("  上次复位原因: %s (code %d)\n", rrName, (int)rr);
  Serial.println(F("  LED: 绿3闪=正常上电   红狂闪=上次欠压复位"));
  Serial.println(F("============================================================="));
  Serial.println(F("  body-cooler  --  ESP32-S3 全身降温器固件"));
  Serial.printf ("  build %s %s\n", __DATE__, __TIME__);
  Serial.println(F("============================================================="));
  Serial.printf("chip       : %s rev%d, %d cores @ %u MHz\n",
                ESP.getChipModel(), ESP.getChipRevision(), ESP.getChipCores(),
                (unsigned)getCpuFrequencyMhz());
  Serial.printf("flash      : %u MB    psram: %u bytes\n",
                (unsigned)(ESP.getFlashChipSize() / (1024 * 1024)),
                (unsigned)ESP.getPsramSize());
  inputs.begin();          // 输入层要在控制器之前初始化
  sensors.begin();
  pump.begin();            // 先 begin，才能拿到 NVS 里持久化的触发电平

  const bool ah = pump.relayActiveHigh();
  Serial.println(F("--- pin map ---"));
  Serial.printf("  DS18B20 bus : GPIO%-2d (4.7k 上拉到 3V3)\n", PIN_ONEWIRE);
  Serial.printf("  relay pump  : GPIO%-2d (%s触发，输出 %s = 泵开)\n", PIN_RELAY_PUMP,
                ah ? "高电平" : "低电平", ah ? "HIGH" : "LOW");
  Serial.printf("  relay aux   : GPIO%d %d %d %d\n", PIN_RELAY_AUX1, PIN_RELAY_AUX2, PIN_RELAY_AUX3, PIN_RELAY_AUX4);
  Serial.printf("  buzzer      : GPIO%-2d   status LED: GPIO%d\n", PIN_BUZZER, PIN_STATUS_LED);
  Serial.printf("  继电器 IN   : 实测 %s     控温总开关 %s（持久化）\n",
                digitalRead(PIN_RELAY_PUMP) ? "HIGH" : "LOW",
                pump.enabled() ? "ON" : "OFF");
  if (!pump.enabled()) {
    Serial.println(F("  !! 上次是 enable off 关掉的，重启后依然是关的。要控温请发: enable on"));
  }
  Serial.println(F("  极性接反的症状：说 pump=ON 却不吸合 / 说 pump=OFF 反而一直转。"));
  Serial.println(F("  现场改极性: relay high | relay low     实测极性: relay test"));
  Serial.println(F("-------------------------------------------------------------"));
  inputs.setFlowCal(pump.cfg().flowPpl);   // 用持久化的标定值覆盖默认值
  console.begin();

  Serial.printf("DS18B20     : 总线发现 %d 个探头\n", sensors.count());
  if (sensors.count() == 0) {
    Serial.println(F("  !! 没找到温度探头 —— 自动控温会被安全联锁锁住（state=FAULT）。"));
    Serial.println(F("  !! 台架测试可用: pump on / pump auto 手动驱动继电器。"));
  }
  Serial.println(F("  --- 可选输入状态 ---"));
#if ENABLE_BATT_SENSE
  Serial.printf("  电池采样    : 启用  当前 %.2f V %s\n", inputs.batteryV(),
                inputs.batteryValid() ? "" : "(未接线？)");
#else
  Serial.println(F("  电池采样    : 关闭"));
#endif
#if ENABLE_FLOW_SENSOR
  Serial.printf("  水流传感器  : 启用  标定 %u 脉冲/升\n", (unsigned)inputs.flowCal());
#else
  Serial.println(F("  水流传感器  : 关闭"));
#endif
#if ENABLE_LEVEL_SWITCH
  Serial.printf("  液位开关    : 启用  当前 %s\n", inputs.levelOk() ? "有水" : "缺水");
#else
  Serial.println(F("  液位开关    : 关闭"));
#endif
#if ENABLE_ESTOP
  Serial.printf("  急停按钮    : 启用  当前 %s\n", inputs.estopLatched() ? "已按下" : "正常");
#else
  Serial.println(F("  急停按钮    : 关闭"));
#endif
#if ENABLE_LEAK_SENSOR
  Serial.println(F("  漏水检测    : 启用"));
#else
  Serial.println(F("  漏水检测    : 关闭"));
#endif
  if (pump.mode() == MODE_BENCH) {
    Serial.println(F(""));
    Serial.println(F("  ========================================================"));
    Serial.printf ("  ==  台架测试模式 BENCH  ==  每 %lu 秒开泵 / %lu 秒停泵\n",
                   (unsigned long)(pump.cfg().benchOnMs / 1000),
                   (unsigned long)(pump.cfg().benchOffMs / 1000));
    Serial.println(F("  ==  已绕过安全联锁：不看探头、不看水温、不管缺水"));
    Serial.println(F("  ==  >> 泵必须有水可抽，绝不允许长时间干转 <<"));
    Serial.println(F("  ==  停：enable off / pump off / 断电池"));
    Serial.println(F("  ==  退出：mode 0  （回到正常控温）"));
    Serial.println(F("  ========================================================"));
    Serial.println(F(""));
  }
  Serial.println(F("  输入 help 看命令表；status 看状态。"));
  Serial.printf("settings    : target=%.2fC band=%.2fC mode=%s  minOn=%lus minOff=%lus  relay=%s\n",
                pump.cfg().targetC, pump.cfg().bandC,
                pump.mode() == MODE_BENCH ? "BENCH" : (pump.mode() == MODE_DUTY ? "DUTY" : "HYSTERESIS"),
                (unsigned long)(pump.cfg().minOnMs / 1000),
                (unsigned long)(pump.cfg().minOffMs / 1000),
                pump.relayActiveHigh() ? "HIGH-on" : "LOW-on");
  Serial.println(F("============================================================="));
}

// ---------------------------------------------------------------------------
//  循环耗时探针：主循环被谁拖慢了，用 diag 命令一看便知
// ---------------------------------------------------------------------------
uint32_t g_loopCount  = 0;
uint32_t g_stageUs[6] = {0, 0, 0, 0, 0, 0};
uint32_t g_lastLoopUs = 0;
uint32_t g_maxLoopUs  = 0;

void loop() {
  const uint32_t t0 = micros();
  uint32_t tPrev = t0;

  // 检测继电器状态变化 -> 绿闪 + 强制重画图案
  {
    bool r = pump.pumpOn();
    if (r != g_lastRelay) {
      g_lastRelay = r;
      g_edgeUntil = millis() + 260;
      if (millis() >= g_bootUntil) blinkForce(PAT_EDGE, sizeof(PAT_EDGE)/sizeof(PAT_EDGE[0]), 0, 70, 0);
    }
  }
  uint32_t tNow = micros(); g_stageUs[0] += tNow - tPrev; tPrev = tNow;
  inputs.tick(millis());
  tNow = micros(); g_stageUs[1] += tNow - tPrev; tPrev = tNow;
  sensors.tick();
  tNow = micros(); g_stageUs[2] += tNow - tPrev; tPrev = tNow;
  pump.tick();
  tNow = micros(); g_stageUs[3] += tNow - tPrev; tPrev = tNow;
  console.tick();
  tNow = micros(); g_stageUs[4] += tNow - tPrev; tPrev = tNow;
  ledUpdateForState();
  blinkTick();
  buzzerTick();
  tNow = micros(); g_stageUs[5] += tNow - tPrev;

  g_lastLoopUs = micros() - t0;
  if (g_lastLoopUs > g_maxLoopUs) g_maxLoopUs = g_lastLoopUs;
  g_loopCount++;
}

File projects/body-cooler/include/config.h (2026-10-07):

// =============================================================================
//  config.h  --  引脚分配 / 可调参数 / 编译期开关
//
//  板子：ESP32-S3 DevKitC-1 (N16R8)
//
//  【硬性禁用的引脚】这些碰了就出问题：
//    GPIO 0 / 45 / 46  strapping 脚，上电电平决定启动模式
//    GPIO 3            JTAG 源选择 strapping
//    GPIO 19 / 20      原生 USB D- / D+
//    GPIO 26 ~ 32      内部 SPI flash
//    GPIO 33 ~ 37      OPI PSRAM（N16R8 用了就丢 8MB PSRAM）
//    GPIO 43 / 44      UART0，接板载 CH343 串口桥
//
//  【可用引脚】1 2 4 5 6 7 8 9 10 11 12 13 14 15 16 17 18 21 38 39 40 41 42 47 48
//  一共 25 个。详细映射见 docs/GPIO-MAP.md
// =============================================================================
#pragma once
#include <Arduino.h>

// ============================ 板级版本 ======================================
// rev1 = 已经烧录验证过的基础接线
// rev2 = rev1 + 新增输入（电池电压 / 水流 / 液位 / 急停 / I2C）
//
// **rev2 不移动任何 rev1 已有引脚**，是纯超集 —— 升级不需要重新接线，
// 只是在空闲引脚上多接几根线。
#define BOARD_REV  2

// ================================ 引脚 ======================================
// ---- rev1 已有（rev2 完全沿用，不要改）----
#define PIN_ONEWIRE        4    // DS18B20 单总线（5 个探头并联），4.7k 上拉到 3V3
#define PIN_RELAY_PUMP     5    // 继电器 1 -> 365 隔膜泵
#define PIN_RELAY_AUX1     6    // 继电器 2 -> 备用（风扇 / 二号泵）
#define PIN_RELAY_AUX2     7    // 继电器 3 -> 备用
#define PIN_RELAY_AUX3     15   // 继电器 4 -> 备用
#define PIN_RELAY_AUX4     16   // 继电器 5 -> 备用 / 主电源总闸
#define PIN_BUZZER         17   // 有源蜂鸣器（可选，不接也行）
#define PIN_LEAK_SENSOR    18   // 漏水检测
#define PIN_STATUS_LED     48   // 板载 WS2812 状态灯

// ---- rev2 新增（全部落在 rev1 没用的空闲脚上）----
#define PIN_BATT_ADC       1    // ADC1_CH0 电池电压分压
#define PIN_AUX_ADC        2    // ADC1_CH1 备用模拟输入（泵电流 / 压力）
#define PIN_I2C_SDA        8    // I2C 数据（OLED / INA219 / SHT30）
#define PIN_I2C_SCL        9    // I2C 时钟
#define PIN_FLOW           10   // 水流传感器（霍尔脉冲）
#define PIN_LEVEL          11   // 液位开关（浮子簧片）
#define PIN_ESTOP          21   // 总电源开关状态检测（可选，不用可空着）
#define PIN_BTN_A          38   // 按键 A（模式 / 配网）
#define PIN_BTN_B          39   // 按键 B（手动强制降温）

// 注意：GPIO 1 ~ 10 同时是 ADC1_CH0 ~ CH9。
// 电池采样必须走 ADC1 —— ESP32-S3 的 ADC2 在 WiFi 开启时不可用。
#define PIN_IS_ADC1(p)  ((p) >= 1 && (p) <= 10)

// ESP32-S3-DevKitC-1 v1.0 板载的是 WS2812 彩灯（GPIO48），普通 digitalWrite
// 点不亮它。如果你的板子是普通单色 LED，把这里改成 0。
#define LED_IS_WS2812      1

// ============================ 继电器有效电平 ================================
// 5V 光耦继电器模块分「高电平触发(H)」和「低电平触发(L)」两种，外形几乎一样，
// 有些模块板上还有跳线帽可以切换。
//
//   RELAY_ACTIVE_HIGH = 0  ->  ESP32 输出 LOW  = 泵开（低电平触发模块 L）★本项目
//   RELAY_ACTIVE_HIGH = 1  ->  ESP32 输出 HIGH = 泵开（高电平触发模块 H）
//
// ★ 实测确认：把模块的 IN 和 GND 短接，继电器吸合 -> 低电平触发(L)。本项目用 0。
//
// ★ 这里只是「出厂默认值」。运行时会从 NVS 读，串口 `relay high` / `relay low`
//   可以当场切换并保存，不用重新编译。
//
// ★ 安全电阻（复位期间 GPIO 是高阻，IN 悬空可能误吸合）：
//     低电平触发模块 -> IN 用 10k 上拉到 VCC(5V)   ★本项目
//     高电平触发模块 -> IN 用 10k 下拉到 GND
// ★★ 低电平触发模块必须用【开漏驱动】，不要用推挽：
//       吸合 = 引脚推低 0V        释放 = 引脚变高阻（悬空）
//   **绝对不要在释放时推 3.3V** —— 模块 VCC 是 5V，光耦 LED 的阴极接在 IN 上，
//   IN 停在 3.3V 时 LED 上还有 5-3.3-1.2≈0.5V 的压差，微弱电流足以把继电器维持住，
//   表现就是「固件说 pump=OFF，泵却一直转」。ESP32 又推不出 5V，推挽永远关不干净。
//   引脚高阻时 LED 没有回路 -> 彻底截止。
//
//   建议配一只 10k：模块 IN ──[10k]── 模块 VCC(5V)，把悬空状态明确拉到 5V，抗电机干扰。
//   串口 `relay pp` 可以切回推挽（高电平触发模块才需要推挽）。
#define RELAY_ACTIVE_HIGH  0

// ============================ 可选输入总开关 ================================
// 这些功能默认全部关闭：**没接线时引脚悬空会误报，板子会一直停在 FAULT**。
// 接好一根线、验证过读数，再打开对应的开关。
#define ENABLE_LEAK_SENSOR  0   // 漏水检测
#define ENABLE_BATT_SENSE   0   // 电池电压
#define ENABLE_FLOW_SENSOR  0   // 水流传感器
#define ENABLE_LEVEL_SWITCH 0   // 液位开关
#define ENABLE_ESTOP        0   // 急停按钮

// ============================ 漏水检测 ======================================
// 背包底部放两根相距 2~3mm 的裸铜线（不要镀锡，锡会钝化）。遇水导通 -> 立即
// 停泵并在串口/蜂鸣器报警。锂电池和水在同一个背包里，这条线值 2 毛钱。
#define LEAK_ACTIVE_LOW     1   // 1 = 遇水把引脚拉低（配内部上拉）

// ============================ 电池电压检测 ==================================
// 3S 锂电 12.6V 满 / 11.1V 标称 / 9.0V 空。分压到 2V 以内再进 ADC：
//   BAT+ ---[R1 100k]---+---[R2 18k]--- GND
//                       |
//                       +--- GPIO1（并在 R2 上跨一个 100nF，降低采样阻抗）
// 分压比 = (100 + 18) / 18 = 6.556  ->  12.6V 对应 1.92V，留足余量
#define BATT_DIV_R1_KOHM   100.0f
#define BATT_DIV_R2_KOHM    18.0f
#define BATT_DIV_FACTOR    ((BATT_DIV_R1_KOHM + BATT_DIV_R2_KOHM) / BATT_DIV_R2_KOHM)

#define BATT_FULL_V        12.60f   // 3S 满电
#define BATT_WARN_V        10.50f   // 3.50V/cell，该准备换电池了
#define BATT_STOP_V         9.60f   // 3.20V/cell，强制停泵保护电芯
#define BATT_ABSENT_V       6.00f   // 读不到这个值就是分压没接（ESP32 自己都要
                                    // 7V 以上才转得起来，不可能真这么低）
#define BATT_RECOVER_V      0.40f   // 恢复回差
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

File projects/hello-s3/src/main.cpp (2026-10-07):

/*
 * hello-s3 -- ESP32-S3-N16R8 bring-up / smoke test
 *
 * Proves, on real silicon, that the whole toolchain is correctly wired:
 *   - the image boots from the 16 MB QIO flash
 *   - the octal (OPI) PSRAM is detected and usable
 *   - the CH343 UART bridge carries a 115200 baud console
 *   - the onboard addressable LED toggles
 *
 * Build:   .\scripts\pio.ps1 run  -d .\projects\hello-s3
 * Upload:  .\scripts\pio.ps1 run  -d .\projects\hello-s3 -t upload
 * Monitor: .\scripts\pio.ps1 device monitor -d .\projects\hello-s3
 */

#include <Arduino.h>
#include <esp_system.h>
#include <esp_chip_info.h>
#include <esp_flash.h>
#include <esp_heap_caps.h>
#include <esp_mac.h>
#include <esp_arduino_version.h>

#ifndef LED_PIN
#define LED_PIN 48
#endif

static void printBanner() {
  Serial.println();
  Serial.println(F("+------------------------------------------+"));
  Serial.println(F("|  hello-s3  ESP32-S3-N16R8 smoke test     |"));
  Serial.println(F("+------------------------------------------+"));
}

static void printChipInfo() {
  esp_chip_info_t chip;
  esp_chip_info(&chip);

  Serial.printf("chip model      : %s (%d core%s)\n",
                chip.model == CHIP_ESP32S3 ? "ESP32-S3" : "other",
                chip.cores, chip.cores == 1 ? "" : "s");
  // esp_chip_info() leaves this at 0 on ESP32-S3 with IDF 4.4 -- it is NOT
  // the revision esptool prints.  esptool reads the eFuse directly and reports
  // the authoritative value ("Chip is ESP32-S3 (QFN56) (revision v0.2)") during
  // upload, so treat that line as the source of truth.
  Serial.printf("chip revision   : %u (esp_chip_info; see esptool upload log)\n",
                (unsigned)chip.revision);
  Serial.printf("cpu frequency   : %u MHz\n", (unsigned)(getCpuFrequencyMhz()));
  Serial.printf("xtal frequency  : %u MHz\n", (unsigned)(getXtalFrequencyMhz()));
  Serial.printf("sdk version     : %s\n", ESP.getSdkVersion());
  Serial.printf("arduino core    : %d.%d.%d\n",
                ESP_ARDUINO_VERSION_MAJOR, ESP_ARDUINO_VERSION_MINOR, ESP_ARDUINO_VERSION_PATCH);

  uint32_t flashSize = 0;
  if (esp_flash_get_size(NULL, &flashSize) == ESP_OK) {
    Serial.printf("flash size      : %u MB\n", (unsigned)(flashSize / (1024 * 1024)));
  }

  uint8_t mac[6] = {0};
  esp_read_mac(mac, ESP_MAC_WIFI_STA);
  Serial.printf("wifi mac        : %02X:%02X:%02X:%02X:%02X:%02X\n",
                mac[0], mac[1], mac[2], mac[3], mac[4], mac[5]);
}

static void printPsramInfo() {
  size_t psram = ESP.getPsramSize();
  if (psram > 0) {
    Serial.printf("psram           : %u bytes total, %u bytes free\n",
                  (unsigned)psram, (unsigned)ESP.getFreePsram());
  } else {
    Serial.println(F("psram           : NOT DETECTED"));
    Serial.println(F("                  check board_build.arduino.memory_type = qio_opi"));
  }

  Serial.printf("heap (internal) : %u bytes free\n", (unsigned)ESP.getFreeHeap());
  Serial.printf("heap (largest)  : %u bytes\n",
                (unsigned)heap_caps_get_largest_free_block(MALLOC_CAP_INTERNAL));
}

static bool psramAllocationSelfTest() {
  if (ESP.getPsramSize() == 0) return false;

  const size_t kBytes = 1024 * 1024;  // 1 MB out of the 8 MB part
  uint8_t *buf = (uint8_t *)heap_caps_malloc(kBytes, MALLOC_CAP_SPIRAM);
  if (buf == nullptr) {
    Serial.println(F("[FAIL] could not allocate 1 MB from PSRAM"));
    return false;
  }

  // Walking-bit pattern: catches address-line faults that a plain memset misses.
  bool ok = true;
  for (size_t i = 0; i < kBytes; i += 4096) {
    buf[i] = (uint8_t)(i / 4096);
  }
  for (size_t i = 0; i < kBytes; i += 4096) {
    if (buf[i] != (uint8_t)(i / 4096)) { ok = false; break; }
  }
  heap_caps_free(buf);

  Serial.println(ok ? F("[ OK ] 1 MB PSRAM read/write test passed")
                    : F("[FAIL] PSRAM read/write test mismatch"));
  return ok;
}

void setup() {
  Serial.begin(115200);
  delay(1500);  // let the CH343 host-side port settle

  pinMode(LED_PIN, OUTPUT);
  digitalWrite(LED_PIN, LOW);

  printBanner();
  printChipInfo();
  printPsramInfo();
  psramAllocationSelfTest();

  Serial.printf("reset reason   : %d\n", (int)esp_reset_reason());
  Serial.println(F("------------------------------------------"));
  Serial.println(F("boot OK -- heartbeat follows"));
}

void loop() {
  static uint32_t tick = 0;
  static bool ledOn = false;

  ledOn = !ledOn;
  digitalWrite(LED_PIN, ledOn ? HIGH : LOW);

  Serial.printf("tick %lu  heap=%u  psram_free=%u  led=%s\n",
                (unsigned long)tick++,
                (unsigned)ESP.getFreeHeap(),
                (unsigned)ESP.getFreePsram(),
                ledOn ? "on" : "off");

  delay(1000);
}

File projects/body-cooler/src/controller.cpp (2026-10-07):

#include "controller.h"
#include "inputs.h"
#include <Preferences.h>

PumpController pump;

static const char* NVS_CFG   = "bc_cfg";
static const char* NVS_STATS = "bc_stats";

PumpController::PumpController()
    : m_state(ST_STANDBY), m_warn(WARN_NONE), m_enabled(true), m_force(FORCE_AUTO),
      m_relayOn(false), m_prevOn(false), m_safetyLatched(false),
      m_lastTick(0), m_onSince(0), m_offSince(0), m_curOnMs(0),
      m_totalRunMs(0), m_startCount(0), m_iceRunStart(0), m_lastDuty(0.0f),
      m_statsDirty(false), m_statsLastSave(0),
      m_benchStart(0), m_benchDone(0), m_bucketIdx(0), m_bucketAcc(0) {
  m_reason[0] = 0;
  snprintf(m_latchReason, sizeof(m_latchReason), "未触发");
  m_testLeft = 0; m_testOn = false; m_testNext = 0;
  m_guardLatched = false; m_guardUntil = 0;
  snprintf(m_guardReason, sizeof(m_guardReason), "未触发");
  applyDefaults();
  for (uint8_t i = 0; i < BUCKETS; i++) m_bucketRun[i] = 0;
}

void PumpController::applyDefaults() {
  settings = settingsDefaults();
}

// ---------------------------------------------------------------------------
//  启动：关键顺序 —— 必须先写输出电平，再切成 OUTPUT。
//  ESP32 复位后 GPIO 默认是高阻输入，如果先 pinMode 再 digitalWrite，
//  中间那几微秒继电器可能被误触发，泵会「啪」地抽一下。
// ---------------------------------------------------------------------------
void PumpController::begin() {
  // ★ 先把 NVS 里的设定读出来（尤其是触发电平），再配置 IO ——
  //   否则会先按编译期默认电平驱动一次 IN，极性选错时泵会「啪」地抽一下。
  loadSettings();
  loadStats();

  const int off = offLevel();

  if (settings.openDrain && !settings.activeHigh) {
    // 开漏：上电就停在高阻，外部 10k 会把 IN 拉到 5V -> 继电器不吸合
    pinMode(PIN_RELAY_PUMP, INPUT);
    m_enabled = settings.enabled;
    m_relayOn = false; m_prevOn = false;
    m_offSince = millis(); m_lastTick = millis();
    return;
  }

  // 低电平触发时，先把内部上拉打开再切输出：
  // 从复位到这一步之间 GPIO 是高阻，内部上拉能让 IN 保持高 -> 继电器不吸合。
  // 高电平触发时反过来用内部下拉，让 IN 保持低。
  if (settings.activeHigh) {
    pinMode(PIN_RELAY_PUMP, INPUT_PULLDOWN);
    digitalWrite(PIN_RELAY_PUMP, off);
  } else {
    pinMode(PIN_RELAY_PUMP, INPUT_PULLUP);
    digitalWrite(PIN_RELAY_PUMP, off);
  }
  digitalWrite(PIN_RELAY_PUMP, off);
  pinMode(PIN_RELAY_PUMP, OUTPUT);
  digitalWrite(PIN_RELAY_PUMP, off);

  const int auxPins[4] = {PIN_RELAY_AUX1, PIN_RELAY_AUX2, PIN_RELAY_AUX3, PIN_RELAY_AUX4};
  for (int i = 0; i < 4; i++) {
    pinMode(auxPins[i], settings.activeHigh ? INPUT_PULLDOWN : INPUT_PULLUP);
    digitalWrite(auxPins[i], off);
    pinMode(auxPins[i], OUTPUT);
    digitalWrite(auxPins[i], off);
  }

  m_enabled = settings.enabled;
  m_relayOn = false;
  m_prevOn = false;
  m_offSince = millis();
  m_lastTick = millis();
}

// 泵/继电器当前应该输出的原始电平（IN 引脚电平）
int PumpController::offLevel() const { return settings.activeHigh ? LOW : HIGH; }
int PumpController::onLevel()  const { return settings.activeHigh ? HIGH : LOW; }

void PumpController::setRelay(bool on) {
  m_relayOn = on;

  // 开漏驱动：只对低电平触发模块有意义。
  //   吸合 -> 把脚推成 OUTPUT LOW（灌电流，能吃掉光耦 LED 的电流）
  //   释放 -> 把脚变回高阻 INPUT，让外部 10k 上拉把 IN 拉到模块的 5V
  // 为什么要这样：模块 VCC 是 5V，光耦 LED 的阴极接 IN。
  //   IN 停在 3.3V 时，LED 上还有 5-3.3-Vf 的压差，可能有微弱电流 -> 继电器放不掉。
  //   只有把 IN 真正拉到 5V 才能彻底截止。ESP32 推不出 5V，但高阻 + 上拉可以。
  if (settings.openDrain && !settings.activeHigh) {
    if (on) {
      pinMode(PIN_RELAY_PUMP, OUTPUT);
      digitalWrite(PIN_RELAY_PUMP, LOW);
    } else {
      pinMode(PIN_RELAY_PUMP, INPUT);   // 高阻，别用内部上拉（只有 3.3V，不够）
    }
    return;
  }

  pinMode(PIN_RELAY_PUMP, OUTPUT);
  digitalWrite(PIN_RELAY_PUMP, on ? onLevel() : offLevel());
}

void PumpController::setOpenDrain(bool on) {
  settings.openDrain = on;
  setRelay(false);          // 立刻按新驱动方式放到「释放」
  saveSettings();
}

// 切换触发电平：先无条件把 IN 拉到「不吸合」电平，再改设定、落盘。
// 这样即使原来极性选错导致继电器一直吸合，一条命令就能立刻放掉。
void PumpController::startRelayTest(uint8_t toggles) {
  m_testLeft = (int8_t)toggles;
  m_testOn   = false;
  m_testNext = millis();
  setRelay(false);          // 先停在「释放」电平
  Serial.printf("[RELAY TEST] 开始：每 5 秒把 GPIO%d(IN) 翻一次，共 %u 次。\n",
                PIN_RELAY_PUMP, (unsigned)toggles);
  Serial.println(F("[RELAY TEST] 记下「哪一次听到咔哒/泵动」以及万用表读数 -> 决定 relay high 还是 low"));
  Serial.println(F("[RELAY TEST] 如果一次咔哒都没有（一直吸着或一直松着）-> IN 那根线没接在 GPIO5 上"));
  Serial.println(F("[RELAY TEST]   -> 拔下来直接插到 ESP32 的 GND 脚试：吸合就说明模块和 ESP32 共地正常"));
}

void PumpController::setRelayPolarity(bool activeHigh, bool persist) {
  settings.activeHigh = activeHigh;
  m_relayOn = false;
  digitalWrite(PIN_RELAY_PUMP, offLevel());
  if (persist) saveSettings();
}

void PumpController::setEnabled(bool on) {
  m_enabled = on;
  settings.enabled = on;
  saveSettings();          // 持久化：上次关掉的，重启后依然是关的（安全）
  if (!on) {
    setRelay(false);
    m_state = ST_STANDBY;
  }
}

void PumpController::setMode(uint8_t m) {
  if (m > MODE_BENCH) return;
  settings.mode = m;
  if (m == MODE_BENCH) { m_benchStart = millis(); m_benchDone = 0; }
}

void PumpController::forcePump(int8_t v) {
  if (v < -1 || v > 1) return;
  m_force = v;
  if (v == FORCE_AUTO) {
    m_offSince = millis();   // 交回自动时重新计最短停机
  }
}

void PumpController::clearFault() {
  m_guardLatched = false;
  m_safetyLatched = false;
  inputs.clearLatches();      // 漏水 / 急停 都是锁存故障，必须显式复位
  m_warn &= ~(WARN_SKIN_LOW | WARN_WATER_LOW | WARN_SENSOR_FAULT | WARN_NO_SENSOR);
}

const char* PumpController::stateName() const {
  switch (m_state) {
    case ST_STANDBY:  return "STANDBY";
    case ST_MONITOR:  return "MONITOR";
    case ST_REST:     return "REST";
    case ST_PUMPING:  return "PUMPING";
    case ST_FAULT:    return "FAULT";
    default:          return "?";
  }
}

String PumpController::warnString(uint32_t w) {
  if (w == WARN_NONE) return String("OK");
  String s;
  if (w & WARN_SKIN_HIGH)       s += "SKIN_HIGH ";
  if (w & WARN_SKIN_LOW)        s += "SKIN_LOW ";
  if (w & WARN_WATER_LOW)       s += "WATER_LOW ";
  if (w & WARN_WATER_HIGH)      s += "WATER_HIGH ";
  if (w & WARN_NO_SKIN_SENSOR)  s += "NO_SKIN_SENSOR ";
  if (w & WARN_NO_WATER_SENSOR) s += "NO_WATER_SENSOR ";
  if (w & WARN_NO_SENSOR)       s += "NO_SENSOR ";
  if (w & WARN_DRY_RUN)         s += "DRY_RUN ";
  if (w & WARN_ICE_MELT)        s += "ICE_MELT ";
  if (w & WARN_SENSOR_FAULT)    s += "SENSOR_FAULT ";
  if (w & WARN_LEAK)            s += "LEAK ";
  if (w & WARN_ESTOP)           s += "ESTOP ";
  if (w & WARN_LEVEL_LOW)       s += "LEVEL_LOW ";
  if (w & WARN_BATT_LOW)        s += "BATT_LOW ";
  if (w & WARN_BATT_CRIT)       s += "BATT_CRIT ";
  if (w & WARN_NO_FLOW)         s += "NO_FLOW ";
  s.trim();
  return s;
}

float PumpController::duty10min() const {
  uint32_t run = 0;
  for (uint8_t i = 0; i < BUCKETS; i++) run += m_bucketRun[i];
  uint32_t total = (uint32_t)BUCKETS * BUCKET_MS;
  if (total == 0) return 0.0f;
  return (float)run / (float)total;
}

void PumpController::dutyWindow(uint32_t now) {
  uint8_t idx = (uint8_t)((now / BUCKET_MS) % BUCKETS);
  if (idx != m_bucketIdx) {
    m_bucketRun[m_bucketIdx] = m_bucketAcc;   // 归档旧桶
    m_bucketAcc = 0;
    m_bucketIdx = idx;
  }
  if (m_relayOn) m_bucketAcc += DEF_TICK_MS;
}
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

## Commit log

2026-10-07 feat: ESP32 全身降温器固件 + 全套文档 + 3D 打印防折护套
    固件 projects/body-cooler
    - DS18B20 多探头异步采集 + 角色映射。修掉 NVS 键名 21 字符超过 15 字符上限
    导致角色静默写入失败、重启即丢失、安全联锁锁死水泵的 bug（改用 r<i>/m<i> 短键）
    - scan 不再清空内存角色；map 立即落盘；扫描后按 ROM 回贴角色
    - 水泵控温状态机：回差 / 时间比例 / 台架测试三种模式
    - 继电器触发电平运行时可切（relay high|low）并支持开漏驱动：
    吸合推低 0V、释放引脚高阻。修掉「固件说 pump=OFF 却一直转」
    —— 5V 光耦模块的 LED 阴极接 IN，推 3.3V 时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
    [sleeve_A_flex.stl, sleeve_A_short.stl, sleeve_B_mid.stl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]
2026-10-09 feat(cad): 转角导弯件 —— 转角用预弯硬质导槽，不再靠软管自己弯
    直护套在转角处仍要靠自身弯曲，反复弯会疲劳开裂；而且软管一折就瘪，
    瘪了以后泵有压力也撑不开 -> 憋压 -> 烧泵。
    新增一族「已经弯好的」开口导槽件，管子走进去就是弯的，不存在折的机会：
    bend_180_R25 180 度 中心半径 25mm 管距 50mm 主力件，蛇形回折
    bend_90_R25 90 度 中心半径 25mm 直角拐弯
    bend_45_R25 45 度 中心半径 25mm 小角度转向
    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
    [bend_180_R18.stl, bend_180_R25.stl, bend_45_R25.stl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]
2026-10-09 docs(cad): 用实测 STL 尺寸修正转角件表格，补 stl_bbox.py 复核脚本
2026-10-09 docs: 补接线口述（控制端 + 输入端，逐条接线表，不含电容）；修正 GPIO-MAP 里过时的触发电平说明
2026-10-09 feat(hardware): 原理图源文件（KiCad 旧版格式，嘉立创EDA 可直接导入）
    为什么用旧格式：嘉立创EDA 的导入文档明确写着「仅支持 KiCAD v4.06 及以上」，
    且「v5.1.3 后的版本文件格式有更新，可能会导入失败」，并且导入原理图必须
    打成 zip 且带库文件。所以生成 EESchema v4 的 .sch + .lib，已打包成 zip。
    内容：控制端 + 输入端完整原理图，32 个元件、101 段导线、94 个网络标签。
    遵守的规则（按你的要求）：
    - 每一处点对点连接都有网络标签（同名网络 = 必须手工接的一根线）
    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
    [body-cooler.sch]
2026-10-09 fix(hardware): 符号引用改用标准「工程库名:符号名」写法，LIBS 行列两个库 —— 修导入后元件不显示
    [body-cooler.sch]
2026-10-09 docs: 逐触点接线总表 WIRING-CHECKLIST.md（85 根线逐根列：丝印对照、上电前 10 查、8 处高频接错、接完验证步骤）
2026-10-09 docs(wiring): 接线总表改为逐触点标识 —— 新增 ESP32 J1/J3 逐脚对照表；所有端点改成物理触点（J1 第 N 脚 / IN 端子 / 红VDD），不再用丝印
2026-10-11 docs(wiring): 接线总表改用五列固定格式（元件名称/触点/连接到元件/连接到触点/说明），ESP32 触点用 GPIO 名
2026-10-11 fix(cad): 护套改成对开两半可打印版 —— 旧版竖打接触面仅55mm2且是弹性螺旋，必然炒面；新版平底465mm2、高5.8mm、零悬垂
2026-10-11 feat(cad): 转角件可打印版 —— 对开两半半壳沿圆弧扫掠，180/90/45 度 + R18；平放零悬垂、同件翻面成对
2026-10-11 fix(cad): 转角件旧版 bend_*.stl 是圆管躺放、底面73度悬垂必然炒面；新增对开半壳 halfbend_*（平底零悬垂）。含逐层宽度实测数据
2026-10-17 fix(cad): 截面改为方底+顶面半圆槽(12宽x7高R0.8)；README 重写为单份干净文档(原堆了5版互相矛盾)；端面改耳切三角化，7件全部水密
2026-10-17 fix(cad): 按实际管子 D9xD10(壁厚0.5) 重算截面 —— 槽口 8.6 改成 10.6，外形 12x7 改成 14x8；转角件同步放大
